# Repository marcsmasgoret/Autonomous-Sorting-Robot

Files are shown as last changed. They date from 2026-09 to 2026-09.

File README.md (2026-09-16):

**1. Problem Statement:**

The objective of this project is to design and develop a fully autonomous mobile robot capable of operating within a defined arena to locate, collect, and sort target objects under a strict 120-second time constraint. The robot must identify and collect green erasers while distinguishing them from non-target objects, then return to a designated home base where the objects are deposited and correctly sorted to maximize scoring performance. The system must function without any external control or intervention, relying entirely on onboard sensing, actuation, and control systems. The design is constrained by factors including limited operation time, physical size restrictions, onboard power supply, and the requirement for reliable autonomous navigation and object handling. The robot must efficiently traverse the arena, avoid obstacles, and consistently return to the base for deposition, while maintaining accurate sorting of collected objects. Scoring is directly dependent on both the quantity of target objects collected and the accuracy of their classification, making both efficiency and precision critical performance metrics. This problem reflects real-world engineering challenges in autonomous robotics, such as industrial material sorting, warehouse automation, and hazardous environment operations, where systems must operate independently and reliably without human intervention. The difficulty of the task lies in the integration of multiple subsystems—navigation, collection, sensing, and sorting—within tight constraints, while ensuring consistent performance despite uncertainties such as object positioning, sensor limitations, and mechanical interactions.

**2. Design Requirements & Constraints:**

The design requirements were developed to ensure that both the mobile robot and the stationary sorting system operate effectively within the given project constraints. The system integrates navigation, collection, and sorting subsystems, each with specific performance targets. Key requirements such as autonomous operation, reliable navigation using an IMU, and accurate color-based sorting guided the selection of components and overall system architecture. Feasibility of the design was validated through iterative prototyping and testing. Mechanical adjustments, including improved scoop clearance and weight reduction, enhanced system performance and reduced actuator load. Additionally, the use of a stationary sorting system improved classification reliability by providing controlled sensing conditions. Overall, the design meets the functional requirements within the constraints of time, power, and system complexity. Key quantitative constraints include a maximum operation time of 120 seconds, operation within a ~15 m² arena, and achieving a sorting accuracy target of at least 90%. [Design Requirements Table.xlsx](readme-assets/Design-Requirements-Table.xlsx)

**3. Program Plan:**

The project was completed over an eight-week period, following a structured and iterative development process. The timeline began with concept generation and selection, followed by mechanical design and CAD modeling of the chassis and scoop system. Prototype fabrication using 3D printing was then carried out, enabling initial testing of the drive, collection, and sorting subsystems. Testing played a critical role in identifying performance limitations, particularly in the scoop mechanism and object handling process. These issues led to a second design iteration, where mechanical refinements such as improved clearances and weight reduction were implemented. Programming and sensor integration were conducted concurrently with testing, reflecting the iterative nature of the development process. The critical path of the project included CAD modeling, prototype fabrication, and system testing, as delays in these stages directly impacted subsequent development. Overlapping tasks, such as programming and system testing, allowed for continuous refinement and improved overall efficiency. The project timeline also accounted for potential schedule variations and risks. Mechanical issues encountered during the initial prototype required redesign and reprinting, which introduced delays. To mitigate this, buffer time was effectively incorporated within the testing and iteration phases, allowing adjustments to be made without significantly affecting the final deadline. This ensured that system integration, final testing, and documentation were completed in time for the final showcase.
[Weekly Gantt Chart.xlsx](readme-assets/Weekly-Gantt-Chart.xlsx)

**4. Concept Generation:**

The system design was developed by decomposing the overall problem into key subsystems, including drivetrain, navigation, object collection, sorting, and homing. For each subsystem, multiple candidate concepts were generated using a combination of engineering reasoning and structured design approaches. This ensured that the final solution was not based on a single idea but rather selected from a diverse set of technically viable alternatives.

A range of concepts were explored for each major subsystem:

Drivetrain: Four-wheel drive, rear-wheel drive, and skid-steer configurations were considered to balance stability, maneuverability, and control complexity.
Navigation: IMU-based heading control, encoder-based tracking, and open-loop control were evaluated based on accuracy and implementation feasibility.
Object Collection: A scoop with rotary brush, conveyor belt system, and passive plow mechanism were explored to assess collection efficiency and object retention.
Sorting System: Both onboard sorting and a stationary base sorting system were considered, with variations in sensing and object handling mechanisms.
Homing Strategy: Ultrasonic-based positioning and alignment mechanisms were evaluated to ensure reliable return-to-base functionality.

Each concept was developed to the point of technical feasibility, ensuring that all candidate solutions were consistent with project constraints such as autonomous operation, time limitations, and system complexity.

**5. Concept Evaluation & Selection:**

The generated concepts were evaluated using structured engineering decision-making methods to determine the most effective overall system design. Three complete system-level concepts (Concept A, B, and C) were developed by combining different subsystem approaches for drivetrain, navigation, collection, and sorting. An initial Go/No-Go screening matrix was applied to eliminate concepts that failed to meet critical project requirements, such as reliable sorting performance, manageable mechanical complexity, and feasibility within the project timeline. Concepts that exhibited high risk in areas such as jamming, unreliable sorting, or excessive system complexity were rejected at this stage. The remaining concepts were then evaluated using a weighted decision matrix, where each design was assessed against key engineering criteria including collection efficiency, sorting accuracy, autonomous navigation performance, mechanical complexity, risk of failure, manufacturability, and system stability. Each criterion was assigned a relative weight based on its importance to overall system success, and concepts were scored accordingly. Through this evaluation process, Concept C achieved the highest overall score, demonstrating the best balance between performance, reliability, and implementation feasibility. Compared to alternative concepts, it reduced mechanical complexity on the mobile robot while improving sorting accuracy through the use of a stationary sorting system. Additionally, it minimized the risk of jamming and allowed for more controlled object handling during classification. The final selected concept integrates a scoop and rotary brush collection mechanism with IMU-assisted navigation and a stationary vibratory sorting system. This architecture was chosen because it enables efficient object collection while maintaining reliable and consistent sorting performance under controlled conditions, making it the most technically sound solution within the project constraints.

*TABLE 1:* Go/No-Go 

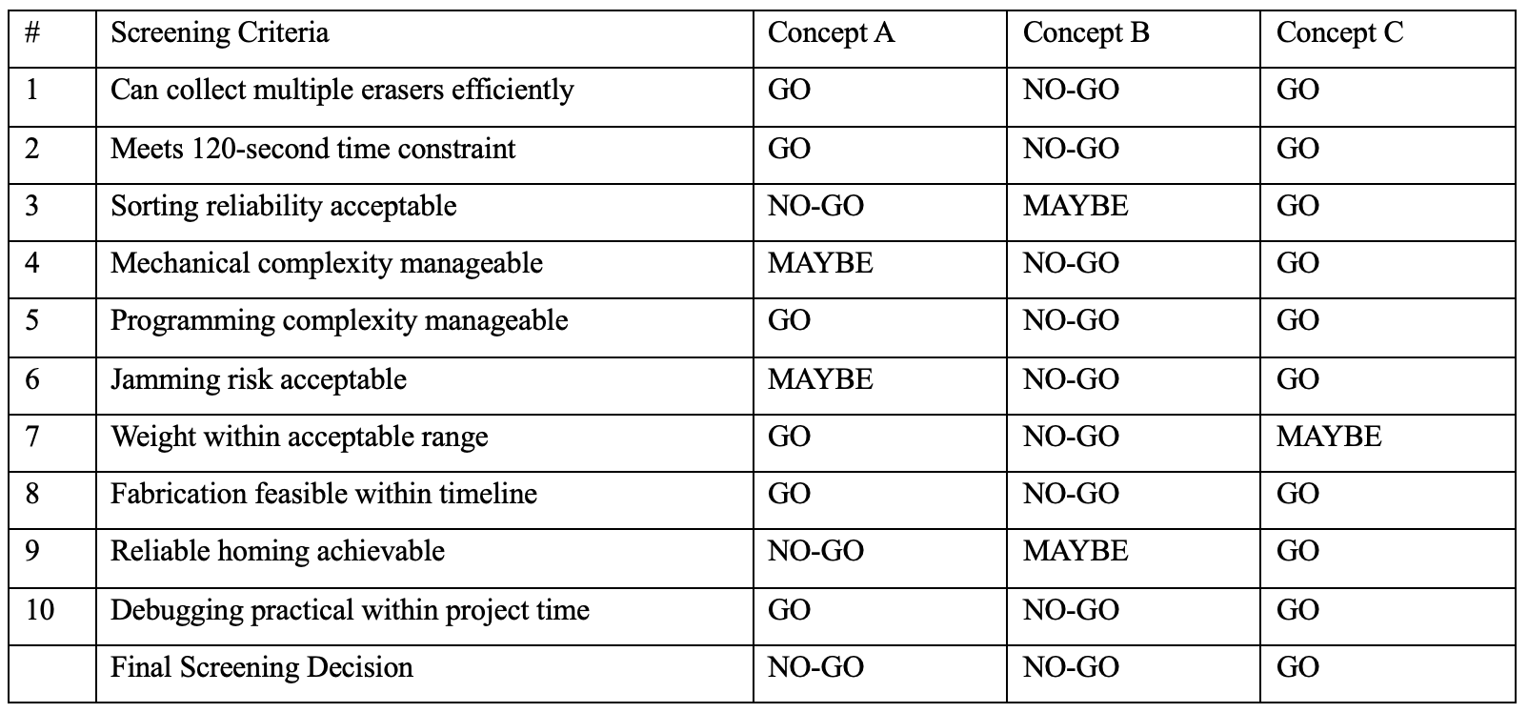
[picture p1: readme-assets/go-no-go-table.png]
Go-NoGo Table


*TABLE 2:* Weighted decision matrix comparing Concepts A, B, and C:

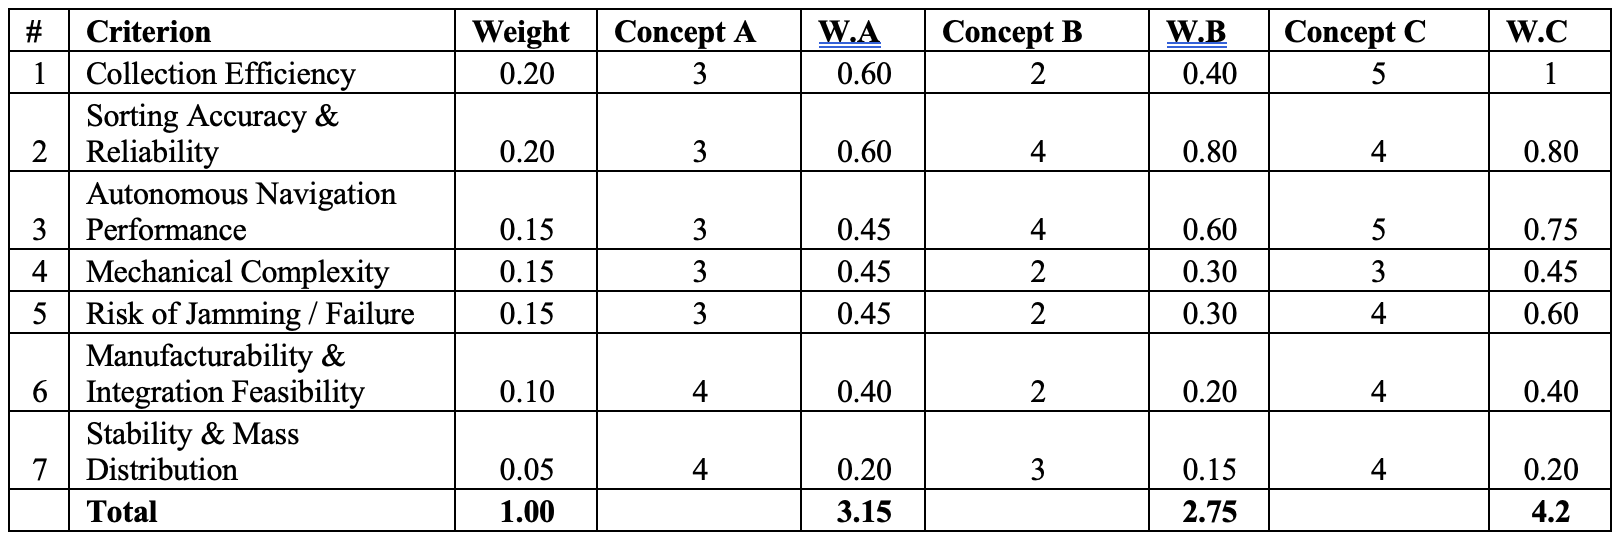
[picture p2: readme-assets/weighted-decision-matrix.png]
Screenshot 2026-04-07 at 11 14 16 AM


**6. Detail Design Development:**

The selected design was refined into a fully detailed system through iterative mechanical, electrical, and control development. The final system consists of a mobile robot for object collection and a stationary base for sorting, with each subsystem designed to meet specific performance requirements. The mechanical structure was developed using CAD modeling, focusing on a lightweight 3D-printed chassis to reduce actuator load while maintaining structural stability. The robot utilizes a rear-wheel drive configuration with two DC gear motors and front support wheels to improve maneuverability and turning accuracy. The scoop mechanism was designed as a servo-actuated lifting system, allowing controlled collection and retention of objects during reverse motion. Iterative redesigns increased internal clearance and reduced interference between components, significantly improving lifting performance and reliability. The collection subsystem integrates a rotary brush mechanism driven by a DC motor, which directs objects into the scoop during forward motion. The brush rotation was refined to reverse direction during backward movement, ensuring objects remain within the scoop and minimizing losses. These refinements were based on observed failures in early prototypes and demonstrate the application of iterative design principles. The navigation and control system incorporates an IMU for heading control and ultrasonic sensing for positioning relative to the base station. A state-based control strategy (collect → return → deposit) was implemented to coordinate system behavior and ensure consistent operation. The sorting subsystem was developed as a stationary system to improve classification accuracy. It consists of a vibrating platform to regulate object flow, a color sensor for detection, and a movable chute mechanism for directing objects. Design refinements addressed issues such as object clustering and sensor misreads by improving flow control and timing, resulting in more reliable sorting performance. All major components, including motors, sensors, structural elements, and actuation systems, were selected based on performance requirements, compatibility, and feasibility within project constraints. The final design demonstrates a fully integrated system where mechanical, electrical, and control subsystems function cohesively to achieve the desired operation.

*FIGURE 1:* Annotated SolidWorks top-view assembly drawing of the final scavenger robot:

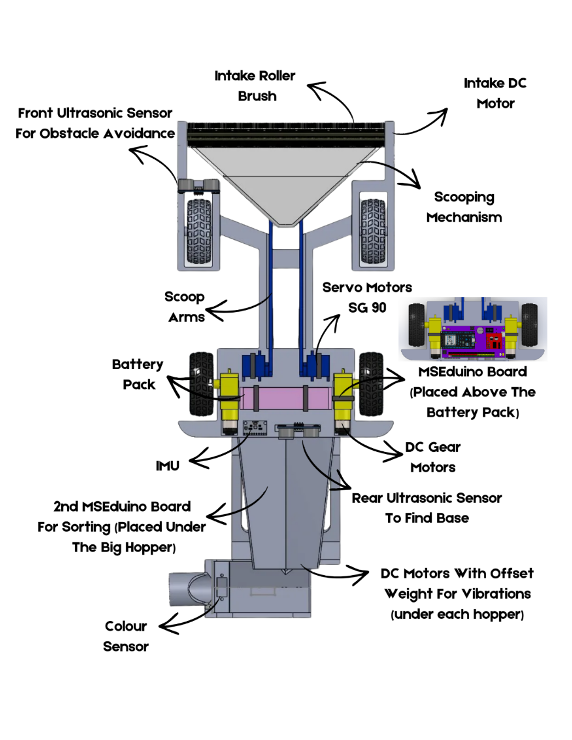
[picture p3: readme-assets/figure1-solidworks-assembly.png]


*FIGURE 2:* Scoop mechanism design evolution:

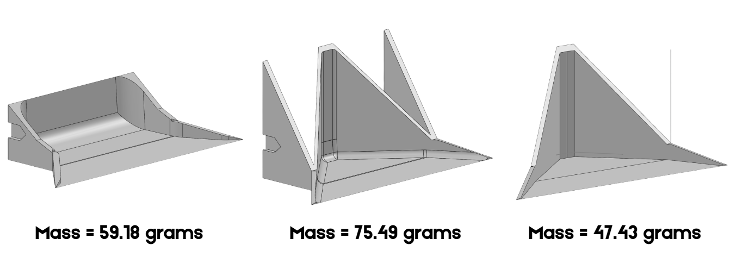
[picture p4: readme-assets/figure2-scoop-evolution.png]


*FIGURE 3:* Sorting System Final Design:

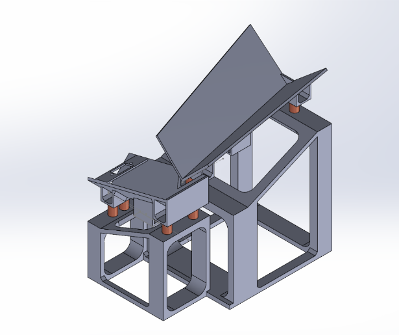
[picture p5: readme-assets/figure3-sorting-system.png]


*FIGURE 4:* System block diagram of the complete autonomous scavenger system:

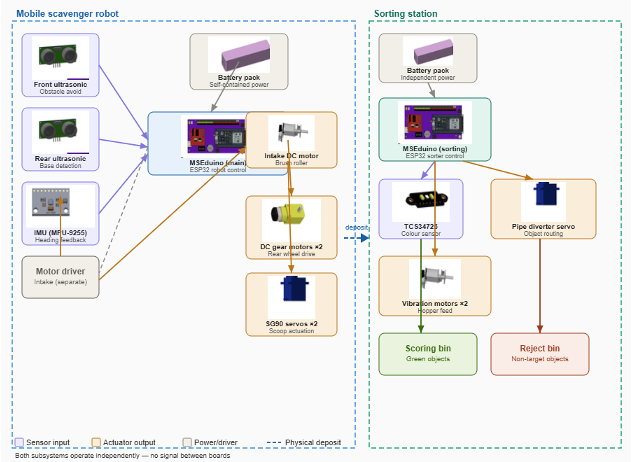
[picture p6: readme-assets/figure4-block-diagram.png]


**7. Design Analysis:**

The performance of the final design was evaluated through a combination of experimental results and engineering analysis of the system’s mechanical and sensing subsystems. The collection mechanism was assessed based on its ability to efficiently gather and retain objects. The rotary brush and scoop system demonstrated effective object capture, with brush rotation directing erasers into the scoop during forward motion. The introduction of reversed brush rotation during backward movement significantly reduced object loss. This indicates that the collection mechanism operates reliably under the expected operating conditions, with performance improvements directly resulting from iterative design refinements. The sorting subsystem was analyzed using calibrated sensor data and threshold-based classification. Experimental results showed that the normalized green value (0.4299) exceeded the detection threshold (0.40) by a margin of 0.10, providing clear separation from non-green objects. Multiple detection conditions were required to be satisfied simultaneously, and a temporal filtering method was implemented to improve robustness. As a result, no misclassification errors were observed across over 1000 tested samples, indicating high classification reliability under controlled conditions. The navigation system was evaluated based on heading stability and return-to-base performance. The use of an IMU enabled consistent orientation control, improving turning accuracy compared to open-loop methods. However, minor deviations in alignment were observed due to sensor drift and cumulative error, indicating moderate confidence in navigation precision. Overall, the system demonstrates high confidence in sorting performance, moderate confidence in navigation accuracy, and good reliability in object collection. The results confirm that the design meets the primary functional requirements, particularly in sorting accuracy and autonomous operation. Compared to alternative approaches such as onboard sorting, the selected stationary sorting system provides significantly improved sensing stability and classification accuracy. While more advanced navigation methods such as SLAM could improve positioning accuracy, they would introduce additional complexity without substantial benefit to overall system performance within the project constraints.

*FIGURE 5:* Calibration Table: The calibration data used to determine detection thresholds and validate color classification performance 

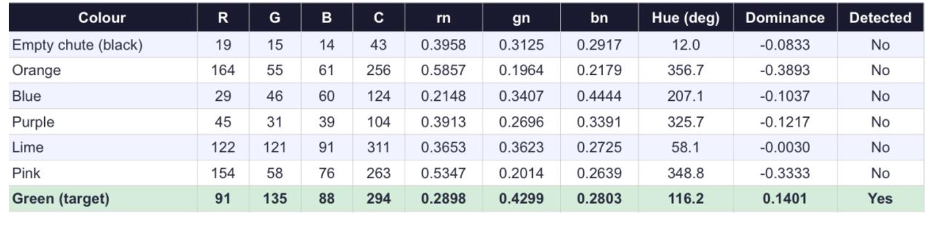
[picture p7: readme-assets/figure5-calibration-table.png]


*FIGURE 6:* Integrated full-system validation results: The integrated system performance results, including sorting accuracy and overall operation time

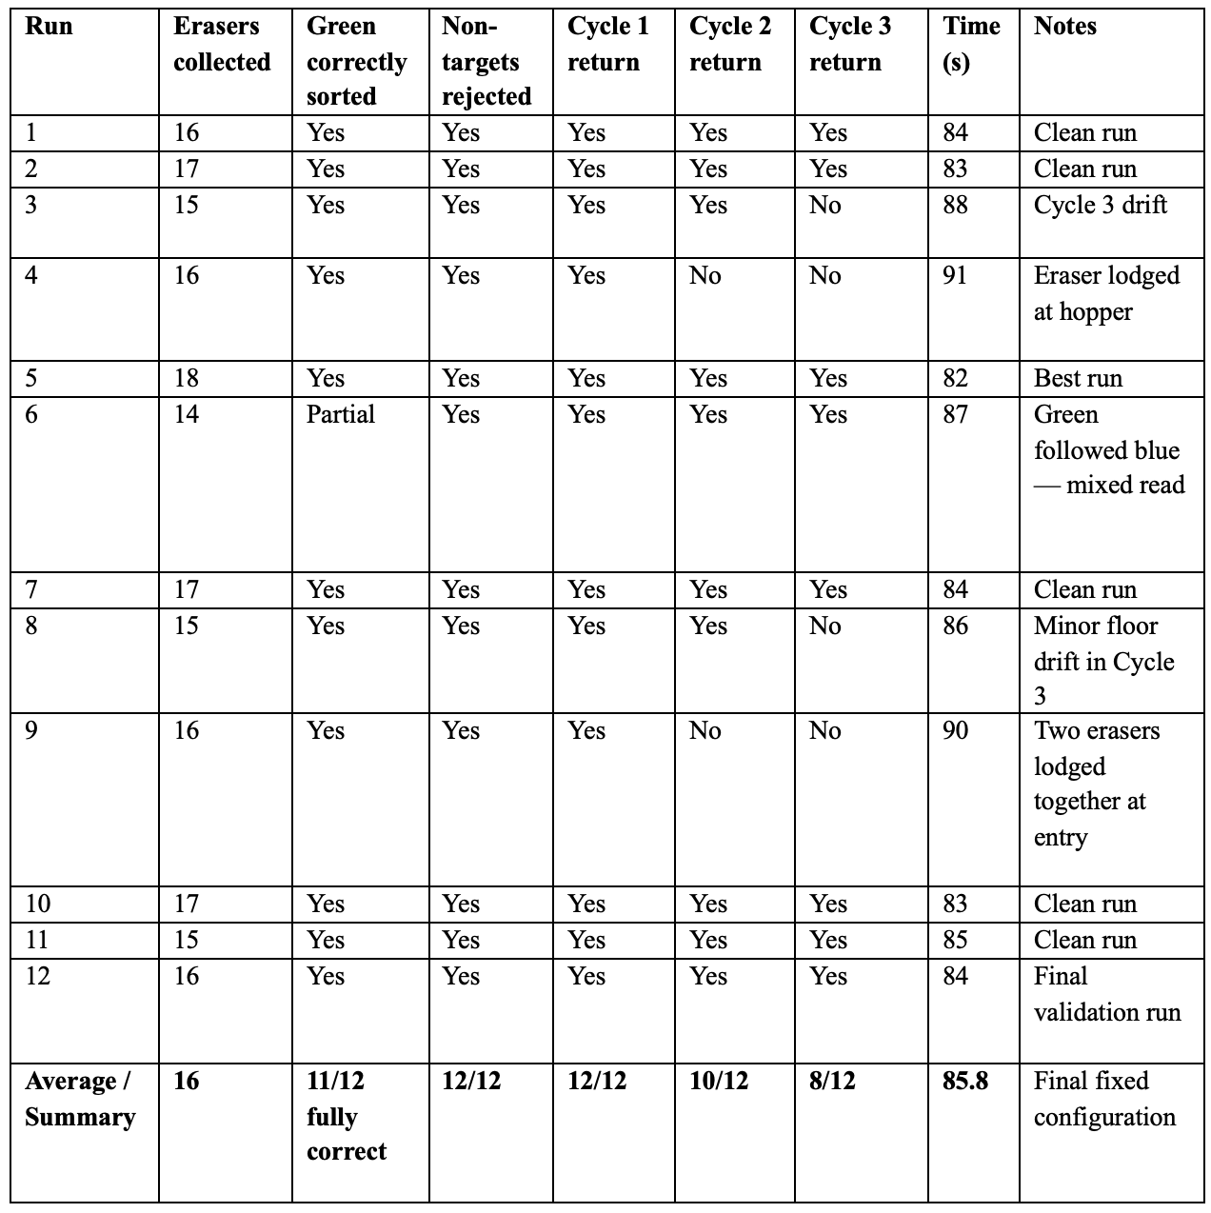
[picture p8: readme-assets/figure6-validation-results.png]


The results are considered valid within the tested conditions, as consistent measurements were obtained across repeated trials under controlled environmental conditions. These findings indicate that the selected design is highly effective for sorting tasks, which is the primary objective of the system. However, the moderate confidence in navigation accuracy suggests that positional errors may affect consistency in more complex environments.

**8. Design Documentation — Mechanical:**

Detailed mechanical design documentation was developed to fully define the final system configuration. This includes CAD models, assembly drawings, and component-level designs that describe the structure, geometry, and integration of all mechanical subsystems. The mechanical design consists of a lightweight 3D-printed chassis, a servo-actuated scoop mechanism, and a rotary brush collection system, all integrated into a stable four-wheel platform. The design was developed using CAD software, allowing for accurate dimensioning, component alignment, and interference checking during the design process. The provided drawings include detailed representations of key components such as the chassis, scoop assembly, brush mounting system, and sorting interface. These drawings define critical dimensions, clearances, and assembly relationships required for proper system operation. Iterative refinements were made to improve mechanical performance, including increased clearance for the scoop mechanism and reduction of excess material to minimize weight and actuator load. The mechanical design follows standard engineering practices, including clear dimensioning, consistent part definition, and organized assembly structure. Consideration was also given to manufacturing constraints, particularly those associated with 3D printing, such as material usage, part orientation, and structural support.

The complete set of mechanical design files is available in the following repository:

- [Engineering Drawings](Final%20CADs%20and%20Drawings/Engineering%20Drawings)  
- [Scavenger Robot CAD Models](Final%20CADs%20and%20Drawings/Scavenger%20CADs)  
- [Sorting System CAD Models](Final%20CADs%20and%20Drawings/Sorter%20CADs)

**9. Design Documentation — Electrical:**

The electrical design documentation defines the complete sensing, actuation, and control architecture of the system. This includes all electronic components, wiring configurations, and signal interfaces required for the operation of both the scavenger robot and the stationary sorting system. The system integrates multiple electronic components, including DC motors for drivetrain and brush actuation, servo motors for scoop and chute movement, an IMU for heading control, ultrasonic sensors for positioning, and a color sensor for object classification. These components are coordinated through a microcontroller-based control system to enable fully autonomous operation. Detailed wiring diagrams and circuit schematics were developed to ensure proper connectivity, power distribution, and signal integrity across all subsystems. Component selection was based on compatibility, performance requirements, and ease of integration within the overall system. Special consideration was given to voltage regulation, current limits, and reliable communication between sensors and actuators. The electrical design follows standard engineering practices, including clear labeling of components, organized wiring layouts, and modular subsystem integration. Consideration was also given to practical implementation constraints such as wiring management, noise reduction, and system reliability during operation.

The complete set of electrical design files is available in the following repository:
- [Control System Code](Final%20Code%20and%20Electrical/Code)
- [Electrical References and Component Documentation](Final%20Code%20and%20Electrical/Electrical%20References)

The bill of materials (BOM) provides a complete list of all mechanical and electrical components used in the system: [Lab 003 Team 1-BOM.xlsx](readme-assets/BOM.xlsx)

**10. Product Evaluation Results:**

The performance of the final system was evaluated through a series of experimental tests designed to assess its ability to meet the primary project objectives, including autonomous operation, object collection, sorting accuracy, and task completion within the required time limit. The system successfully completed the full autonomous operational cycle, demonstrating reliable integration of collection, navigation, and sorting subsystems. The system met the required time constraint and demonstrated strong sorting performance under controlled conditions. The use of a stationary sorting system contributed to improved classification stability and consistency.

The results are summarized in Figure 6, which presents the integrated system performance metrics, and in Table 6, which provides detailed validation results across multiple trials.

Testing was conducted through repeated trials under controlled conditions, with multiple erasers distributed within the arena to evaluate full system performance.

Subsystem testing confirmed that the drivetrain provided consistent motion, IMU-based heading control remained within acceptable drift limits, and ultrasonic sensing enabled reliable stopping near the base. The collection system achieved an average capture rate of 8–9 erasers per pass and maintained object retention during reverse motion. Sorting tests demonstrated accurate classification of green erasers and reliable rejection of non-target objects, with stable operation of the vibration and chute mechanisms.

Key performance results include:
- Task completion time: ~85.7 s (within 120 s requirement)
- Sorting accuracy: ~90–92%
- Misclassification: negligible under controlled conditions

While the system demonstrated strong overall performance, several limitations were identified during testing. Object clustering on the vibrating platform occasionally resulted in multiple erasers being processed simultaneously, which could affect sorting consistency. Additionally, navigation accuracy was influenced by IMU drift, leading to minor misalignment during return-to-base operations.

The results are considered reliable within the tested conditions and demonstrate strong validation of the system’s ability to meet the project objectives; however, performance may vary under different environmental conditions or increased system complexity.

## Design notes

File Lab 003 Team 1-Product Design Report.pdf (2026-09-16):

## Western University

## Faculty of Engineering

## Mechatronic Systems Engineering Program

## MSE 2202 – Introduction to Mechatronic Design

## Product Design Report

## Scavenger Robot Project: Welcome to Servo Buster

Lab 003 – Team 1

Group Members

Youssef El Kabat — 251370760

Marc Masgoret — 251412418

Eric Halim — 251241625

Dalia Salamah — 251402061

Date: April 2, 2026

Executive Summary

This report presents the design, development, and validation of an autonomous scavenger system for the

MSE 2202 term project. The objective was to design a compact, self-powered system capable of

autonomously collecting erasers from an unmarked arena, returning them to a base station, and sorting

target green erasers from non-target objects within a 120-second time limit.

The final design consisted of two coordinated subsystems: a mobile collection robot and a stationary

sorting subsystem at the base station. The robot used rear-wheel drive, a scoop-and-brush intake, IMU-

assisted navigation, and ultrasonic-based return positioning. The stationary sorter used a dual vibratory

feeder, a TCS34725 colour sensor, and a servo-actuated chute to classify deposited erasers under

controlled conditions. This architecture was selected because it reduced the mechanical complexity of the

robot while improving sorting reliability.

The design evolved significantly through testing and refinement. Major improvements included reducing

chassis weight, redesigning the scoop to lower servo loading, improving alignment at the base station, and

replacing the initial rotary sorting concept with a more reliable vibratory feeder. Validation testing

showed that the final system completed the full sequence of collection, return, unloading, and sorting in

an average of 85.7 s across the final 12 runs. Sorting accuracy reached 90–92% under controlled trials.

The main conclusion is that the final design provided a feasible and technically sound solution to the

project requirements. Future development should focus on improving object retention, return-path

accuracy, and single-file object feeding at the sorting station to further increase reliability and sorting

accuracy.

Table of Contents

1-Introduction

### 1.1 Design Problem

Autonomous robotic systems are increasingly deployed in environments where human operation is

unsafe, inefficient, or impractical — including hazardous material recovery, remote inspection, industrial

automation, and search-and-retrieval applications. In these contexts, the system must do more than

traverse an environment; it must reliably identify, collect, transport, and process objects of interest under

real operating conditions. The design challenge addressed in this project was the development of a

compact, self-powered autonomous scavenger system capable of completing a full collection-and-sorting

task without human intervention.

Per the project requirements, the system had to depart from a defined base location, gather valuable

objects from the ground within an operating area of up to 15 m², return to the base station, and deposit

only the target objects into a collection container — all within a maximum of 120 seconds. The system

was required to operate fully autonomously, with no painted lines, installed guides, tethered power

supplies, or external controllers, and had to be implemented using an ESP32-based microcontroller. The

complete assembly also had to remain compact enough to fit within an MSE locker without disassembly.

The operating surface was assumed to be relatively flat and bounded primarily at its perimeter, with no

major internal obstacles.

Beyond these stated requirements, the actual engineering problem was considerably broader. A successful

design had to simultaneously balance mobility, collection efficiency, object retention, sorting reliability,

manufacturability, mechanical simplicity, power constraints, and robustness under real operating

conditions. These competing demands motivated the adoption of a two-subsystem architecture: a mobile

scavenger robot responsible for navigation and object collection, paired with a stationary sorting

subsystem located at the base station. Although physically separate, the two subsystems were designed to

function as one unified solution. This architecture reduced the mechanical complexity and sensing burden on the mobile platform while improving the feasibility, calibration accessibility, and overall reliability of

the sorting stage.

### 1.2 Background Information

This project required the integration of several core mechatronic disciplines, including autonomous

navigation, ground-level object collection, and colour-based object classification. A review of relevant

approaches informed the final design decisions in each of these areas.

For small autonomous robots operating in bounded indoor environments, common navigation strategies

include dead reckoning, inertial heading control, line-following, infrared beacon homing, and vision-

based localization. Dead reckoning using wheel encoders is straightforward to implement but accumulates

positional error over time due to wheel slip and mechanical tolerances. Line-following eliminates drift but

requires pre-installed guides, which conflicts directly with the project constraints. Infrared beacon homing

offers a practical middle ground: it provides directional feedback toward a known target without requiring

external infrastructure, making it well-suited to the return-to-base phase of this task. For area coverage,

open-loop timed sweep patterns — while less precise than closed-loop localization — are robust,

computationally simple, and sufficient for bounded flat environments where obstacle density is low.

Ground-level object collection mechanisms for small robots include claws, plows, rotating brushes,

conveyor belts, scoops, and vacuum-based systems. Claw mechanisms allow targeted manipulation but

introduce actuation complexity and reduce collection throughput. Vacuum and conveyor systems support

continuous pickup but demand additional power, volume, and fabrication effort. Brush-and-scoop

arrangements represent an effective compromise: they are mechanically simple, tolerant of variability in

object position, and capable of gathering multiple objects rapidly — properties that are well-aligned with

the time-constrained scavenging task defined in this project.

Sorting of small, coloured objects can be achieved using photodiode-based colour sensing, RGB sensors,

or machine vision. RGB colour sensors such as the TCS34725 provide reliable hue discrimination at low

cost and with minimal computational overhead, making them appropriate for embedded systems with

limited processing resources. Sorting can be implemented either onboard the mobile robot or via a

stationary system at the base station. Onboard sorting minimises transfer steps but increases the robot's

weight, sensing complexity, and packaging constraints. A stationary sorter, by contrast, allows objects to

be presented to the sensor in a controlled, repeatable manner, improving classification accuracy and

simplifying calibration. For an academic prototype operating under a fixed budget and timeline, the

stationary approach offers a more reliable and maintainable solution.

More sophisticated approaches — including encoder-based odometry with sensor fusion, simultaneous

localization and mapping (SLAM), or convolutional neural network-based vision classification — could

improve adaptability and spatial precision. However, these methods introduce significant hardware cost,

computational overhead, and development complexity that were inconsistent with the available resources

and project timeline. The final design therefore prioritised practical robustness and subsystem modularity

over algorithmic sophistication.

### 1.3 Project Objectives and Scope

The objective of this project was to design, fabricate, and validate a complete autonomous scavenger

system capable of collecting target objects from an unmarked floor area and ensuring that only the desired

objects were deposited into the final collection container. Functionally, the completed system had to:

1. Navigate autonomously through the operating area without external guides or remote control

### 2. Collect multiple objects from the ground efficiently within the mission time limit

### 3. Transport collected objects back to the base station

4. Sort the collected objects such that only target items were retained in the final collection stage

Expressed in quantitative engineering terms, the system was required to complete the full task within 120

seconds, operate entirely on the onboard power bank included in the MSE 2202 Lab Kit, use an ESP32-

based microcontroller for all control functions, remain within the physical envelope of an MSE locker

without disassembly, and be fabricated within a combined additional component budget of $50. The

project scope encompassed concept generation and selection, CAD-based design development, prototype

fabrication, electrical and software integration, and performance testing against the defined specifications.

These objectives were achievable within the available timeframe because the final architecture

deliberately decomposed the overall mission into two cooperating subsystems — a mobile robot

optimised for navigation and collection, and a stationary sorter optimised for classification and final

deposition — each of which could be developed, tested, and refined in parallel.

### 2. Discussion

### 2.1 Concept Generation and Selection

A structured concept generation process was used to develop the final system architecture. Rather than

selecting a complete robot concept immediately, the overall problem was first decomposed into major

functional subsystems: drivetrain, navigation and heading control, environment sensing, search strategy,

object collection, sorting location, sorting mechanism, homing, object deposition, and structural

packaging. Multiple concepts were generated for each subsystem independently to explore a broad design

space before committing to an integrated solution. This approach ensured that final concept selection was

grounded in engineering trade-offs rather than intuition alone. Alternatives considered during the

Milestone 1 concept generation phase included front-wheel, all-wheel, and three-wheel drive layouts;

open-loop, encoder-based, and IMU-based motion control; random-walk, lawnmower, and spiral

coverage strategies; onboard versus base-station sorting; and multiple collection and deposition

mechanisms.

At the subsystem level, each selected concept was chosen on the basis of its balance between

performance, reliability, simplicity, and feasibility within the course timeline and budget. For locomotion,

a four-wheel all-wheel-drive layout was identified as the preferred concept in Milestone 1 because it

offered improved traction, stability, and turning control while pushing a front-mounted collection

mechanism. For navigation, IMU-based heading feedback was selected over open-loop PWM control and

encoder-based speed matching because it improved directional consistency without introducing the

encoder mounting and tuning challenges associated with wheel-speed feedback on a compact platform. A

single ultrasonic sensor was selected for obstacle detection on the grounds that the competition arena was

assumed to be relatively open and flat, making a simple single-axis sensing configuration sufficient for

safe autonomous operation. A lawnmower-style zig-zag coverage strategy was chosen because it offered

more predictable area coverage than a random walk and lower implementation complexity than a spiral or

perimeter-inward strategy. For sorting, a stationary base-station sorter was preferred over onboard sorting

because it reduced the mass and mechanical complexity of the mobile robot while simultaneously creating

more controlled and repeatable sensing conditions for object colour classification. Within the base-station

sorting category, two distinct mechanisms were evaluated: a motorised rotary indexing disc with radial

ridges intended to capture and index erasers one at a time, and a dual vibratory feeder with a servo-

actuated bifurcated chute. The rotary disc was rejected after physical testing revealed that the compliant

and irregular surface geometry of the erasers prevented consistent single-object indexing, making the

vibratory feeder the stronger candidate.

These selected subsystem concepts were then assembled into three complete system-level concepts for

comparative evaluation. Concept A used a scoop with active intake, infrared beacon homing, and a

gravity-based ramp sorter with a servo-controlled gate. Concept B used a six-wheel skid-steer platform,

claw-based pickup, onboard sorting, and encoder-based homing. Concept C used a four-wheel-drive

chassis, scoop-based collection with active brush intake, IMU-assisted navigation, and a stationary base

sorting station with colour sensing and active servo diversion. Concept C was selected because it provided the strongest overall balance between collection efficiency, sorting reliability, navigation performance,

and integration feasibility. Compared with Concept A, it reduced sensitivity to gravity timing and

trapdoor alignment by using a more controlled vibration-assisted transfer and diverter-based sorting

process. Compared with Concept B, it avoided the high mechanical and programming complexity

associated with claw-based pickup and onboard real-time object discrimination. A Go/No-Go screening

eliminated Concepts A and B due to unacceptable risk in sorting reliability, homing robustness, and

mechanical complexity, while Concept C passed all mandatory screening criteria. This result was

subsequently confirmed by a weighted decision matrix, in which Concept C received the highest total

score of 4.20, compared with 3.15 for Concept A and 2.75 for Concept B.

From an engineering standpoint, the selection of Concept C was justified primarily because it separated

the overall mission into two cooperating but independently optimised subsystems. The mobile robot was

optimised for motion, collection, and return-to-base behaviour, while the stationary sorter was optimised

for controlled object presentation and classification. This separation reduced the number of interacting

mechanisms that had to function simultaneously on the robot, lowered the risk of onboard jamming or

sensing interference, and improved the likelihood of completing the full mission within the 120-second

time constraint. The architecture was also more realistic to fabricate, debug, and refine within the

available time and course resources than either alternative. The concept selection process therefore

identified not only a feasible design direction but also demonstrated why it represented the most

practically sound and technically balanced solution among the candidates considered.

While Concept C was selected as the foundation for further development, the final prototype was not a

direct one-to-one implementation of the original conceptual design. As prototyping and subsystem testing

progressed, several elements of the concept were refined to improve manufacturability, reduce weight,

simplify integration, and increase overall reliability. These refinements included changes to the drivetrain

layout, chassis structure, scoop geometry, unloading method, and collection sequence. Concept C should therefore be understood as the selected design direction, while the final prototype represents its optimised

and experimentally refined implementation.

Table 1: Go/No-Go screening matrix applied to the three system-level design concepts. Concepts A and

B were eliminated due to unacceptable risk in sorting reliability, homing robustness, and mechanical

complexity. Concept C passed all mandatory screening criteria and was selected for further development.

# | Screening Criteria | Concept A | Concept B | Concept C

1 | Can collect multiple erasers efficiently | GO | NO-GO | GO
2 | Meets 120-second time constraint | GO | NO-GO | GO
3 | Sorting reliability acceptable | NO-GO | MAYBE | GO
4 | Mechanical complexity manageable | MAYBE | NO-GO | GO
5 | Programming complexity manageable | GO | NO-GO | GO
6 | Jamming risk acceptable | MAYBE | NO-GO | GO
7 | Weight within acceptable range | GO | NO-GO | MAYBE
8 | Fabrication feasible within timeline | GO | NO-GO | GO
9 | Reliable homing achievable | NO-GO | MAYBE | GO
10 | Debugging practical within project time | GO | NO-GO | GO
| Final Screening Decision | NO-GO | NO-GO | GO

Table 2: Weighted decision matrix comparing Concepts A, B, and C across seven engineering criteria.

Weights were assigned based on relative importance to mission success. Concept C achieved the highest

weighted total score of 4.20, confirming the Go/No-Go screening result.

# | Criterion | Weight | Concept A | W.A | Concept B | W.B | Concept C | W.C

1 | Collection Efficiency | 0.20 | 3 | 0.60 | 2 | 0.40 | 5 | 1
2 | Sorting Accuracy & Reliability | 0.20 | 3 | 0.60 | 4 | 0.80 | 4 | 0.80
3 | Autonomous Navigation Performance | 0.15 | 3 | 0.45 | 4 | 0.60 | 5 | 0.75
4 | Mechanical Complexity | 0.15 | 3 | 0.45 | 2 | 0.30 | 3 | 0.45
5 | Risk of Jamming / Failure | 0.15 | 3 | 0.45 | 2 | 0.30 | 4 | 0.60
6 | Manufacturability & Integration Feasibility | 0.10 | 4 | 0.40 | 2 | 0.20 | 4 | 0.40
7 | Stability & Mass Distribution | 0.05 | 4 | 0.20 | 3 | 0.15 | 4 | 0.20
| Total | 1.00 | | 3.15 | | 2.75 | | 4.2

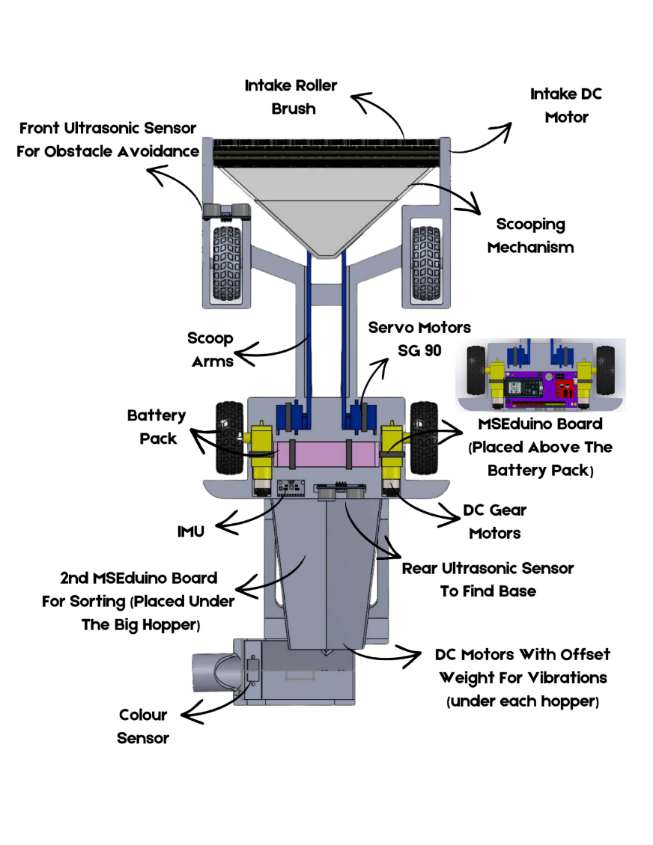
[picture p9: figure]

Figure 1: Annotated SolidWorks top-view assembly drawing of the final scavenger robot, identifying all

major subsystems including the intake roller brush, scooping mechanism, scoop arms, SG90 servo

motors, DC gear motors, IMU, front and rear ultrasonic sensors, battery pack, MSEduino control boards,

and vibration motors.

### 2.2 Detailed Design and System Implementation

The final design comprised two coordinated subsystems: a mobile collection robot and a stationary

sorting station, each optimised for its specific function within the overall mission. The detailed design

process focused on refining both subsystems into a manufacturable and functional final product that could

be built within the available time, budget, and fabrication constraints while operating reliably as one

integrated system.

Mobile Robot — Drivetrain and Chassis

The mobile robot was designed around a compact wheeled chassis with a front-mounted collection

mechanism and a rear section housing the drive system, electronics, and structural support. In the refined

final design, the robot used two powered rear wheels driven by DC gear motors, with passive front support wheels providing stability. Differential motor control enabled forward motion, reversing, and

turning. This rear-wheel-drive layout represented a deliberate simplification from the all-wheel-drive

concept originally selected in Milestone 1. The change was justified on the grounds that the operating

surface was smooth and flat, making the additional traction and mechanical complexity of all-wheel drive

unnecessary. The simplified layout reduced wiring complexity, current draw, and fabrication effort while

maintaining adequate mobility for the defined arena conditions.

The chassis underwent three distinct design iterations during prototyping. The first iteration used a broad

board-style structure with recessed indentations intended to simplify integration of electronic components,

side panels, and the scoop assembly. While functional for early testing, this layout introduced

unnecessary structural material and therefore excessive mass. A second iteration retained the indentation-

based packaging concept but reduced overall thickness and consolidated the component arrangement into

a tighter footprint. Although this improved packaging density, further testing during milestone validation

revealed that the platform could be simplified more substantially. The final chassis adopted a skeletal

structure retaining only the essential load-bearing geometry. Electronics were arranged compactly at the

rear alongside the drive motors, and custom 3D-printed retaining pins secured components without

additional fastener hardware. This progressive mass reduction improved the power-to-weight ratio of the

robot and reduced the actuation load on the scoop-lifting servos.

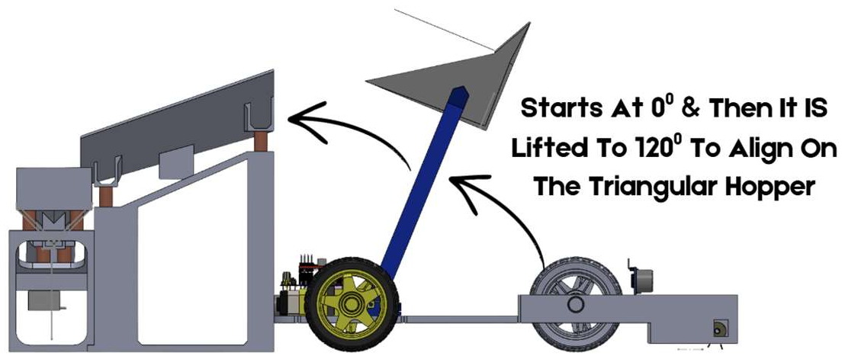
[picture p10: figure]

Figure 2: SolidWorks side-view assembly drawing of the scavenger robot showing the scoop mechanism

in the raised (deposit) position. The arrow indicates the rotational travel of the servo-driven scoop arms

from the lowered collection position to the raised unloading position.

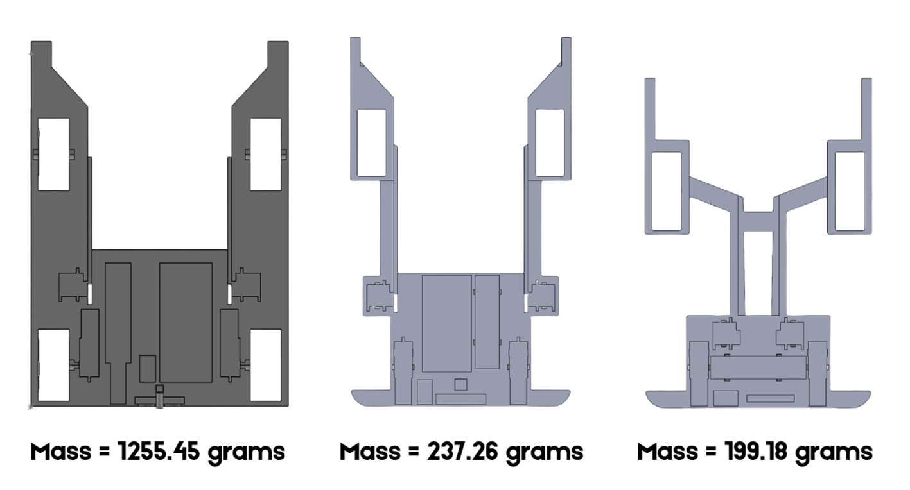
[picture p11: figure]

Figure 3: Chassis design evolution across three prototype iterations. Left: first-generation broad board

chassis with recessed component indentations. Centre: second-generation reduced-thickness chassis with

consolidated component layout. Right: final skeletal chassis retaining only essential load-bearing

geometry, with 3D-printed retaining pins replacing conventional fastener hardware.

Mobile Robot — Object Collection

Object collection was achieved using a front scoop combined with an active rotary brush. The scoop

provided a wide ground-level capture area and funneled erasers toward the intake region as the robot

advanced. The brush, constructed from pipe-cleaner bristles and driven by a DC motor, rotated inward

during forward travel to pull scattered erasers into the scoop more effectively than a passive plow alone.

This arrangement increased collection probability and allowed multiple erasers to be gathered

continuously during a single forward pass. During reverse motion, the scoop was raised and brush

rotation was coordinated to retain collected objects and prevent them from escaping the scoop cavity. This

coordinated scoop-and-brush interaction allowed the same front mechanism to serve both collection and

containment functions, reducing the need for a separate internal transfer system.

The scoop mechanism also underwent substantial redesign between prototype iterations. Early versions

used a wide rectangular scoop supported by arms mounted near the outer edges of the chassis. Testing

revealed two significant problems with this arrangement. First, insufficient arm clearance caused the scoop arms to rub against the chassis structure during lifting, imposing excessive frictional load on the

servos and risking overheating or stall. Second, the scoop's own mass was high enough to challenge servo

lifting capacity before any eraser payload was added. To address both issues, the scoop was redesigned to

be significantly lighter and tapered to better match the triangular entry geometry of the sorting station,

improving unloading efficiency and reducing the probability of erasers missing the vibratory feeder

during the deposition step. The scoop arms were relocated inward toward the chassis centreline to

eliminate wall contact during travel, and their geometry was adjusted to reduce the mechanical tension

generated by an overly wide mounting span. A transverse connecting beam was added between the two

arms, enabling both servo-driven sides to share the lifting load, improving symmetry of motion, and

reducing torsional twisting under payload. Collectively, these changes reduced the effective torque

demand on the servo system and improved the reliability of the lifting and unloading cycle.

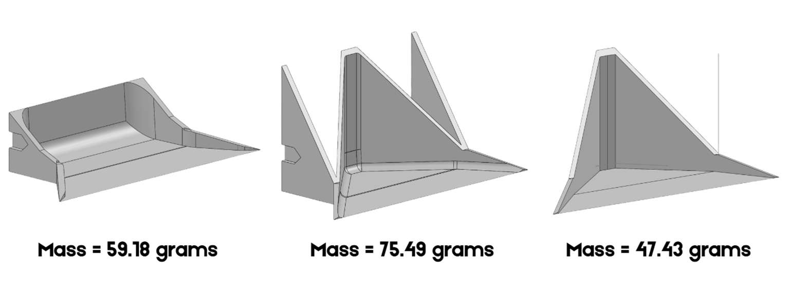
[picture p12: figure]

Figure 4: Scoop mechanism design evolution. Left: original wide rectangular scoop with outboard arm

mounting, which caused chassis wall contact and excessive servo loading during lifting. Right: final

tapered scoop profile with inboard arm relocation, transverse connecting beam, and reduced structural

mass, restoring reliable servo operation within the rated torque margin.

Mobile Robot — Navigation and Return-to-Base

The robot performed search coverage under IMU-assisted heading control, with the strategy evolving

across prototype stages. The initial lawnmower-style zig-zag pattern deposited too many erasers simultaneously and overloaded the scoop servos, and was refined into the three-cycle fan-shaped path

described below. In both implementations, the IMU was calibrated at the start of each run and heading

corrections applied throughout motion to maintain directional consistency. A rear-mounted ultrasonic

sensor detected proximity to the sorting station and triggered the stop-and-deposit sequence. A V-shaped

alignment wall — two flat walls angled at 50 degrees — provided passive lateral correction during

reverse approach: the filleted chassis corners contacted the walls and self-centred the robot without any

active software correction.

Figure 5: SolidWorks drawing of the V-shaped base

station alignment walls, showing the two flat walls

angled at 50 degrees forming a passive docking guide.

The filleted chassis corners of the robot contact and slide

along the walls during reverse approach, self-correcting

any lateral offset until the robot is centred and the

ultrasonic sensor confirms contact with the base.

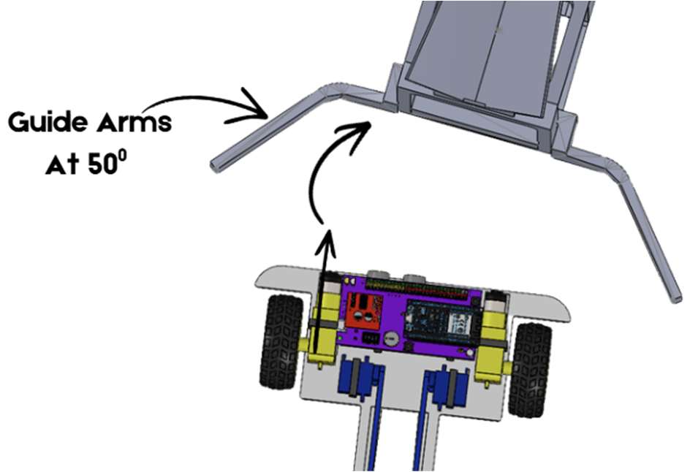
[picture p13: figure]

Collection Strategy — Multi-Cycle Operation

The overall collection strategy was refined during integration testing from a single extended pass to a

multi-cycle sequence of shorter collection-and-deposition runs. In the final control sequence, the robot

began at the base station and executed three distinct collection cycles. Cycle 1 drove straight forward

along the central corridor and reversed directly back to the base to deposit. Cycle 2 turned approximately

45 degrees to the right before advancing forward, then reversed back to the deposit point and realigned.

Cycle 3 mirrored this on the left side. Together, the three cycles formed a fan-shaped coverage pattern

across the full width of the arena, as shown in Figure 6. This staged approach offered two key engineering

advantages. First, it allowed the sorting mechanism to begin processing earlier deposits while the robot

continued collecting, improving the effective use of the 120-second mission window. Second, it capped

the maximum scoop payload per cycle, reducing peak servo loading and preventing the sorter from being overwhelmed by a large simultaneous deposit. In practice, this multi-cycle strategy improved both

mechanical reliability and sorting throughput consistency.

Figure 6: Motion sequence diagram showing the

three-cycle collection path executed by the robot

within the operating arena. Cycle 1 follows a

straightforward-and-return path along the central

corridor; Cycles 2 and 3 follow right and left

diagonal paths respectively, forming a fan pattern

that covers the full arena width. Solid lines

indicate forward collection passes; dashed lines

indicate reverse return to the base station.

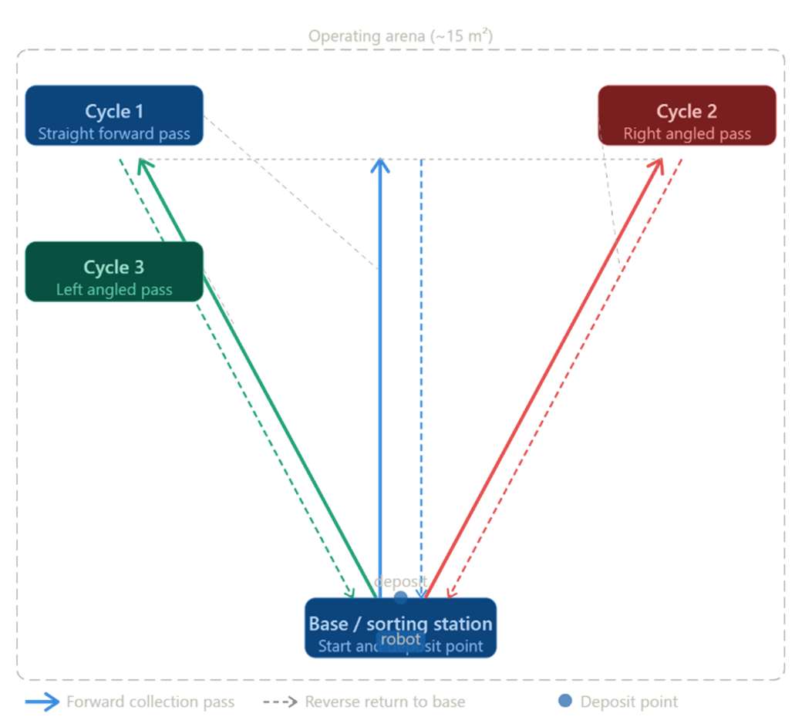
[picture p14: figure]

Sorting System:

Once the mobile robot deposited its collected load at the base station, object classification and final

deposition were handled entirely by the stationary sorting subsystem. The sorting station underwent a full

architectural redesign between prototype stages after early testing revealed that the initial concept could

not provide reliable single-object presentation to the sensor. The final design process therefore focused on

selecting a sorting mechanism that could be fabricated with available resources, tuned experimentally, and

integrated consistently with the unloading behaviour of the robot.

The initial sorting concept used a motorized rotary indexing disc mounted on an inclined tripod frame,

with extruded radial ridges sized to capture one eraser at a time. As the disc rotated, erasers were intended

to be captured in the inter-ridge pockets and indexed individually into a blast-gate assembly, where a

TCS34725 colour sensor would trigger a servo-actuated chute to sort them left (non-target) or right

(green). However, physical testing showed that this concept could not reliably isolate individual erasers.

Due to the compliant surface and irregular orientation of the erasers, the ridges would sometimes capture multiple objects or none. Without a controlled upstream feeding mechanism, the system could not

guarantee one-at-a-time delivery and was therefore rejected in favour of a different architecture.

Figure 7: Initial rotary indexing disc sorting concept.

The final sorting station used a dual-stage vibratory feeder, a

colour sensing stage, and a servo-actuated bifurcated output

chute. Each of the two inclined funnel platforms was driven by a

DC motor mounted beneath it and supported by stiff compression

springs, which provided the restoring force for consistent

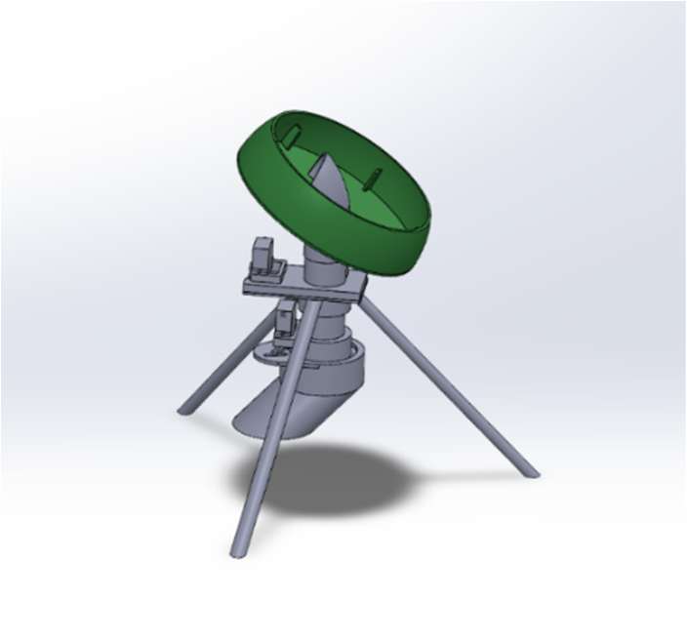
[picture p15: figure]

oscillatory motion. The stock 400:1 gearboxes were removed from both motors so the shafts could rotate

at higher speed, and an eccentric offset weight was attached to each shaft to generate high-frequency

vibration. This vibration disaggregated clustered erasers and promoted progressive single-file

advancement toward the sensing chute. The final sorting station was built primarily from 3D-printed

structural components and integrated a TCS34725 colour sensor for object classification, two modified

DC motors with eccentric masses for vibratory feeding, stiff compression springs for controlled

oscillation, and a servo-actuated chute for final object diversion. These components were selected because

they provided a practical balance between simplicity, tunability, and reliable operation within the

available fabrication methods and project budget.

Figure 8: Final dual vibratory feeder sorting system.

Funnel angle proved to be a critical tuning parameter.

Initial steep angles generated excessive eraser momentum

and caused clustering at the sensing stage. After iterative

testing, an angle of 16° from horizontal was established as

optimal for both funnels, allowing gravity-driven

advancement at a controlled rate. The two motors were

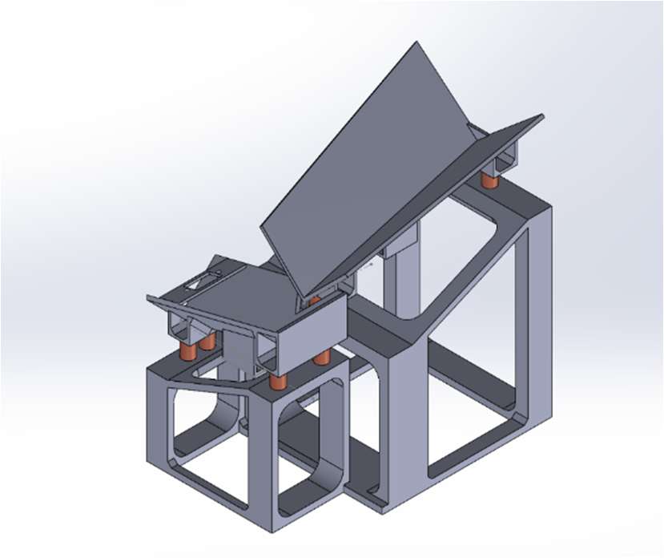
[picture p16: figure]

operated in an alternating offset pattern, with the upper funnel active while the lower was inactive and vice versa, so that erasers arrived at each stage with dissipated momentum. Both motors were driven at

maximum PWM (255/255), which produced the most controlled and repeatable feeding behaviour.

At the base of the lower funnel, the TCS34725 colour sensor classified each eraser using calibrated RGB

threshold values established during sensor testing. In the final implementation, an eraser was classified as

green when the normalized green ratio exceeded 0.40 and the green-dominance term was positive. This

rule was selected because the target green eraser produced a normalized green value of 0.4299 with

positive dominance, while all non-target test objects produced lower normalized green values and non-

positive dominance under the same sensing conditions. Objects that did not satisfy this condition were

rejected by default, ensuring that sensor uncertainty resulted in missed green erasers rather than false

acceptance of non-target objects.

Across 100 successive sorting trials, the final sorting system achieved 90–92% classification accuracy.

The primary failure mode was eraser clustering at the sensing stage, where two objects entering

simultaneously could produce a composite reading and occasional misclassification. A secondary

limitation was base-station drift under sustained vibration, which was temporarily managed during the

showcase by securing the unit to the surface. Despite these limitations, the achieved accuracy was

considered acceptable for the scope of the project.

### 2.3 Design Analysis

The final design was evaluated from the perspectives of collection efficiency, mechanical feasibility,

sorting reliability, and overall system integration. Given the academic project context, the analysis

focused on whether the selected architecture achieved a realistic and defensible balance between

performance and reliability, combining qualitative engineering reasoning with targeted quantitative

assessments where practical measurements were available.

System-Level Architecture

The most consequential design decision was the separation of the full mission into two coordinated

subsystems. By assigning collection, navigation, and transport exclusively to the mobile robot, and classification and deposition exclusively to the stationary sorter, the architecture reduced the number of

simultaneous sensing, actuation, and timing demands placed on any single unit. Relative to the onboard

sorting architecture of Concept B, this arrangement was expected to yield a higher probability of mission

completion within 120 seconds because the robot could optimise for collection speed without also

managing real-time object discrimination. Relative to the passive gravity-fed sorting of Concept A, it

offered greater control over object presentation to the colour sensor, since vibration-assisted feeding and

active servo diversion are less sensitive to ramp angle tolerance and precise gravitational timing than a

purely passive gate system. The sorting station itself also underwent a full internal architectural redesign

between prototype stages, moving from a rotary indexing disc concept to a dual vibratory feeder

arrangement, further demonstrating that the two-subsystem architecture provided the modularity to

completely replace the sorting mechanism without any modification to the mobile robot — validating a

key structural advantage of the selected concept. These comparisons support the conclusion that the

selected architecture represented the most robust, modular, and controllable option among those

evaluated.

Table 3: Quantitative and qualitative performance comparison between the three evaluated system-level

concepts across key engineering criteria. Concept C is the only concept for which validated sorting

accuracy data is available, as Concepts A and B were eliminated prior to prototype construction.

Criterion | Concept A | Concept B | Concept C (Selected)
Weighted decision score | 3.15 | 2.75 | 4.2
Sorting method | Passive gravity gate | Onboard real-time sorting | Dual vibratory feeder
Navigation method | IR beacon homing | Encoder-based return | IMU-assisted heading
Collection method | Active scoop intake | Claw-based pickup | Scoop + brush intake
Sorting architecture iterations | 1 | 1 | 2 (rotary disc → vibratory feeder)
Onboard mechanical complexity | Medium | High | Low–Medium
Jam risk assessment | High | Very high | Low
Sorting accuracy (validated) | Not tested | Not tested | 90–92%
Fabrication feasibility | Medium | Low | High
Passed Go/No-Go screening | No | No | Yes

Figure 9: System block diagram of the autonomous

scavenger system, showing sensor inputs, the

ESP32-based controller, motor driver, actuator

outputs, onboard power supply, and the object

transfer path between the mobile robot and sorting

station.

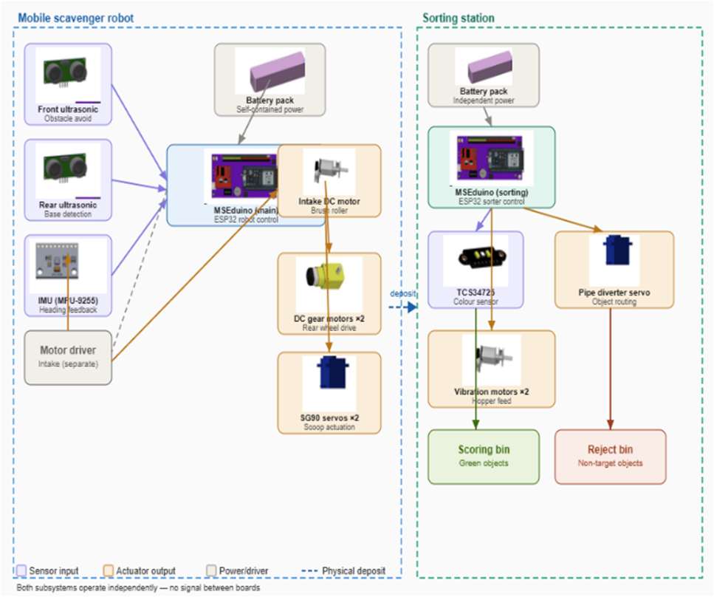
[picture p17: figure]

Mechanical Feasibility — Actuator Loading

A key mechanical concern throughout prototyping was the load imposed on the scoop-lifting servo

system. The SG90 micro servo used for scoop actuation has a rated stall torque of 1.8 kg·cm (176.5

N·mm). Using the static torque relationship T = mgL, where m is the combined scoop and payload mass

and L is the arm length from pivot to load point (178.5 mm), the torque demand of the original design was

calculated as:

T₁ = (0.07549 + 0.018) × 9.81 × 0.1785 = 0.1638 N·m (163.8 N·mm)

This represented 92.8% of the servo's stall torque — a critically small operating margin that directly

explained the observed servo stall failures during early prototype testing. Following the scoop redesign,

the reduced scoop mass of 47.43 g yielded a revised torque demand of:

T₂ = (0.04743 + 0.018) × 9.81 × 0.1785 = 0.1146 N·m (114.6 N·mm)

This corresponds to 64.9% of stall torque, restoring a safe operating margin and representing a 30.0%

reduction in torque demand relative to the original design. The addition of the bilateral connecting

beam between the scoop arms further distributed this load across both servos, improving symmetry and

reducing the risk of asymmetric stall. These calculations confirm that the scoop redesign was not merely a qualitative improvement but a quantitatively necessary correction to bring the actuation system within its

reliable operating range.

Figure 10: Handwritten calculation of servo torque demand before and after scoop redesign. The original

design operated at 92.8% of the SG90 stall torque rating, explaining observed servo stall failures. The

redesigned scoop reduced torque demand to 64.9% of stall torque, representing a 30.0% reduction and

restoring a reliable operating margin.

Sorting Station — Flow Control and Classification Confidence

The sorting station was analysed in terms of object flow regularity and classification reliability. As

described in Section 2.2, the initial rotary disc was abandoned when eraser compliance prevented

consistent single-object indexing. The dual vibratory feeder resolved this by converting bulk deposits into

a controlled single-file stream before the TCS34725

sensing region. Classification confidence depended on

calibrated funnel angle (16 degrees), alternating motor

offset pattern, and maximum PWM (255/255). The fail-

safe default of left-diversion for all unclassified objects

ensured sensor failures produced missed green erasers

rather than non-target contamination. Across 100

successive trials the system achieved 90–92% accuracy,

with simultaneous dual-object arrival as the primary

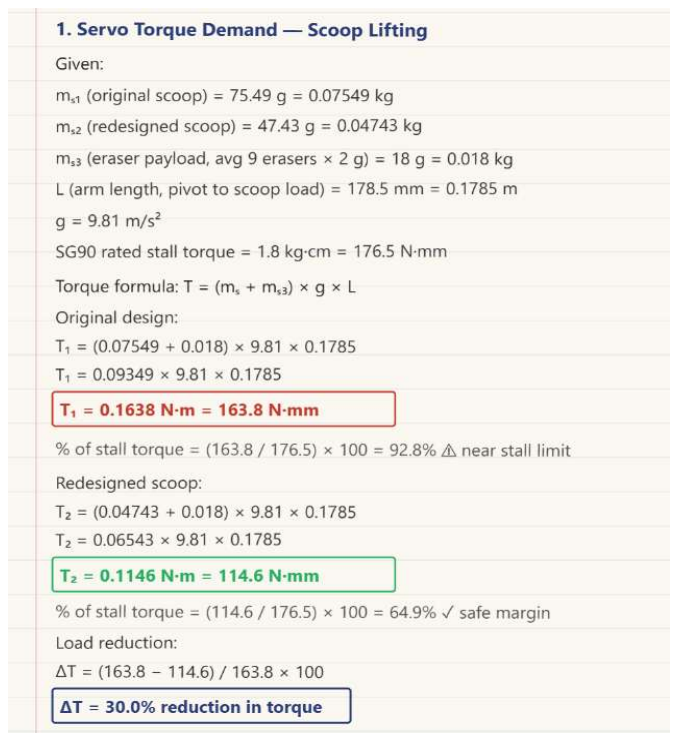
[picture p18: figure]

failure mode.

Multi-Cycle Motion Strategy

The transition from the initial single-pass coverage strategy to the final multi-cycle fan-shaped path

improved system performance in a measurable and quantifiable way. A cycle time budget was constructed

from the measured durations of each operational phase, as shown in Figure 11. Cycle 1 (straight forward pass) totalled 14,000 ms. Cycles 2 and 3 (right and left angled passes respectively) totalled 15,400 ms

each, accounting for the additional in-place turn and realignment manoeuvre. The combined estimated

robot motion time was therefore 44,800 ms (44.8 s). Across three timed full-system runs, the measured

average completion time was (87 + 87 + 83) / 3 = 85.7 seconds, comfortably within the 120-second

mission limit and providing a working margin of 34.3 seconds. The difference between the estimated

44.8s and the measured 85.7s accounts for residual eraser sorting time after robot motion was complete,

confirming that the throughput capacity of the sorting station — rather than robot travel time — was the

primary determinant of overall cycle duration. This has an important design implication: further

improvements to overall system performance would be more effectively achieved by increasing sorting

throughput than by reducing robot travel time.

Figure 11: Handwritten cycle time budget

for the three-cycle fan-shaped collection

sequence. Estimated motion time was 44.8 s,

and the measured average completion time

over 3 runs was 85.7s, leaving a 34.3s margin

within the 120 s limit. The 40.9 s difference

was due to sorting after motion ended.

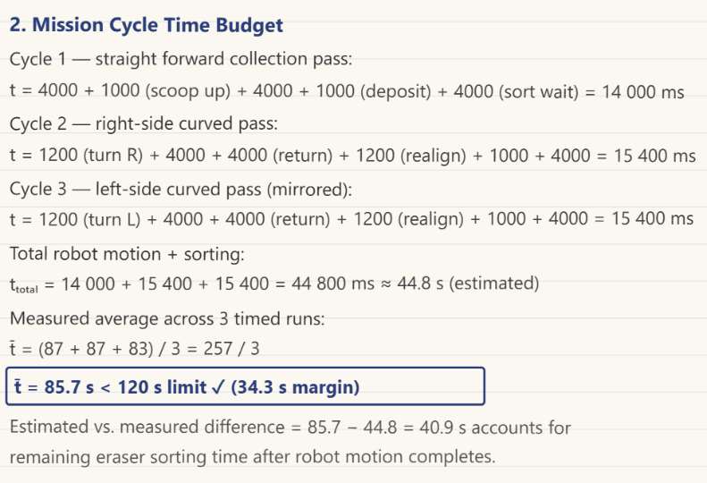
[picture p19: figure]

Overall Confidence Assessment

Confidence in the final design is assessed as moderate to high. The strongest areas are: the two-subsystem

architecture’s demonstrated ability to accommodate a complete sorting mechanism replacement without

modifying the robot; the quantitatively confirmed servo torque reduction from 92.8% to 64.9% of stall;

and empirically validated 90–92% sorting accuracy. Confidence is lower in cycle-to-cycle repeatability

because the system is sensitive to IMU zero-point drift, ultrasonic threshold, vibration intensity, and

colour-sensor thresholds — all of which shift with battery state, lighting, or reassembly. These would be

addressed in a future iteration through tighter tolerances and closed-loop feedback. Nevertheless, the iterative refinement process — spanning three chassis versions, two scoop designs, two sorting

architectures, and a navigation revision — provides clear evidence of rigorous engineering development.

### 2.4 Product Validation

Prototype validation used repeated subsystem and integrated testing to assess whether the design met its

objectives. A total of 86 runs were completed during development, with the final 12 runs using fixed code

and hardware reported here as the most representative of final performance.

Drive System and Navigation Validation

Drive system testing confirmed reliable forward motion, reversing, and turning under battery power with

all mechanisms installed. IMU heading control produced acceptable directional consistency and the robot

returned successfully to the base station across repeated trials. The V-shaped alignment walls

compensated for small heading errors during approach. The rear-wheel-drive layout and IMU navigation

strategy were confirmed sufficient for the arena conditions.

Collection Subsystem Validation

Collection testing confirmed that the original scoop geometry caused servo stall under load. Following the

chassis and scoop redesigns, reducing torque demand from 92.8% to 64.9% of stall, lifting performance

improved substantially and the robot deposited erasers consistently across trials. The tapered scoop also

improved transfer alignment with the sorting station entry, reducing misaligned deposits.

Sorting Station Validation

Sorting station validation confirmed that excessive vibration amplitude or poor track geometry caused

multiple erasers to arrive simultaneously. Iterative adjustment of motor speed and track angle improved

single-object presentation. TCS34725 threshold values were established through calibration trials with

both eraser types under representative lighting conditions, with the RGB ratio threshold set to maximise

discrimination margin. These thresholds were applied consistently across all validation runs.

Integrated System Validation

Integrated testing confirmed that the robot and sorting station executed the complete operational sequence

— collection, return, unloading, and classification — as one coordinated process. Across the 12 final runs,

the system collected an average of 15–17 erasers per sequence, returned from Cycle 1 in all 12 runs,

Cycle 2 in 10 of 12, and Cycle 3 in 8 of 12. The sorting station correctly classified green erasers in 11 of

12 runs; the single misclassification occurred when a green eraser immediately followed a non-target,

producing a mixed reading. Isolated failures were caused by erasers lodging at the hopper entry or minor

floor-drift. The system completed the task within 120 s in all 12 runs at an average of 85.7 s.

Table 4: Robot subsystem test plan and results summary.

Test objective | Method | Pass criterion | Result | Design impact
Drive forward and reverse reliably | Timed straight runs under full load | Consistent travel with no stall | Pass — consistent across all runs | Confirmed rear-wheel-drive layout sufficient
IMU heading consistency | Repeated forward passes measuring lateral drift | Drift < 15 cm over 1 m | Pass — acceptable drift for arena size | IMU calibration procedure standardised
Ultrasonic stopping accuracy | Reverse approach to station, measure stop distance | Stop within ±3 cm of target | Pass — repeatable with fixed threshold | Threshold value fixed in final code
Scoop lifting under load | Lift loaded scoop (9 erasers) 5 consecutive times | No servo stall in 5/5 attempts | Pass after redesign; failed with original scoop | Triggered scoop mass reduction and arm geometry revision
Eraser capture rate | Forward pass over 10 distributed erasers | Capture ≥ 7/10 erasers per pass | Pass — avg 8–9 per straight pass | Brush rotation speed confirmed effective
Eraser retention during reverse | Reverse 4,000 ms with loaded scoop raised | No erasers lost during transit | Pass — coordinated brush stop effective | Brush stop timing confirmed in code

Table 5: Sorting station test plan and results summary.

Test objective | Method | Pass criterion | Result | Design impact
Single-object presentation | Deposit 10 erasers, observe sensor region | ≥ 8/10 arrive individually | Pass after track angle adjustment | Track angle and vibration intensity tuned
Green eraser classification | Present 20 green erasers individually | ≥ 19/20 correctly identified | Pass — 20/20 in calibration trials | RGB threshold value fixed
Non-target rejection | Present 20 non-green erasers individually | ≥ 19/20 correctly rejected | Pass — 20/20 in calibration trials | Threshold margin confirmed adequate
Mixed-colour stream sorting | Deposit mixed batch of 10 erasers | ≥ 8/10 correctly sorted | Pass — 9/10 in mixed stream trials | One misclassification from close succession
Vibration feed continuity | Run station for 120 s continuously | No jams or feed stoppages | Pass — no mechanical stoppages observed | Vibration motor speed confirmed stable

Table 6: Integrated full-system validation results across 12 final runs using the fixed hardware and code

configuration. The system completed the task within the 120-second limit in all runs, with an average

completion time of 85.7 s.

Run | Erasers collected | Green correctly sorted | Non-targets rejected | Cycle 1 return | Cycle 2 return | Cycle 3 return | Time (s) | Notes
1 | 16 | Yes | Yes | Yes | Yes | Yes | 84 | Clean run
2 | 17 | Yes | Yes | Yes | Yes | Yes | 83 | Clean run
3 | 15 | Yes | Yes | Yes | Yes | No | 88 | Cycle 3 drift
4 | 16 | Yes | Yes | Yes | No | No | 91 | Eraser lodged at hopper
5 | 18 | Yes | Yes | Yes | Yes | Yes | 82 | Best run
6 | 14 | Partial | Yes | Yes | Yes | Yes | 87 | Green followed blue — mixed read
7 | 17 | Yes | Yes | Yes | Yes | Yes | 84 | Clean run
8 | 15 | Yes | Yes | Yes | Yes | No | 86 | Minor floor drift in Cycle 3
9 | 16 | Yes | Yes | Yes | No | No | 90 | Two erasers lodged together at entry
10 | 17 | Yes | Yes | Yes | Yes | Yes | 83 | Clean run
11 | 15 | Yes | Yes | Yes | Yes | Yes | 85 | Clean run
12 | 16 | Yes | Yes | Yes | Yes | Yes | 84 | Final validation run
Average / Summary | 16 11/12 | fully correct | 12/12 | 12/12 | 10/12 | 8/12 | 85.7 | Final fixed configuration

Figure 12: Photograph of the fully assembled autonomous scavenger

system during final validation testing, showing the mobile robot

positioned at the sorting station with the scoop in the raised deposit

position and collected erasers entering the vibratory hopper tracks of

the stationary sorting station.

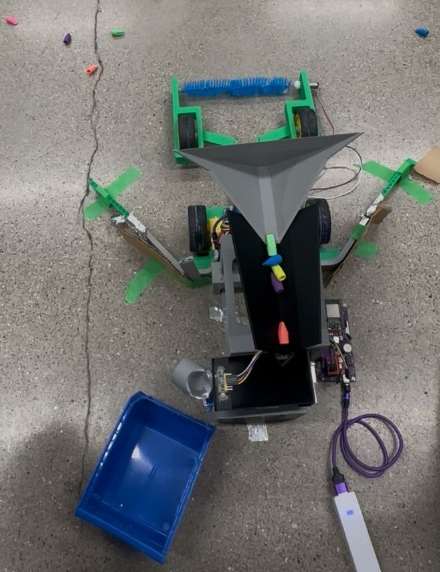
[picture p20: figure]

Validation Limitations

The primary limitations of the validation process were prototype variability and the practical constraints

of the course testing environment. The system remained sensitive to calibration-dependent parameters —

specifically IMU zero-point drift, ultrasonic stopping threshold, vibration intensity, and colour-sensor

thresholds — all of which could shift between sessions due to battery state, ambient lighting, or minor

mechanical reassembly differences. Performance also varied with the initial spatial distribution of erasers

within the arena, and the return success rate for Cycles 2 and 3 was lower than for Cycle 1, reflecting the

greater accumulated heading error over longer and angled paths. As a result, the validation results should

be interpreted as strong evidence of functional feasibility and meaningful improvement relative to earlier

prototype iterations, rather than as demonstration of production-level repeatability. Even so, the testing

programme provided clear and relevant evidence that the final design satisfied the primary project

objectives and that the implemented refinements produced consistent and measurable improvements in

collection, unloading, and sorting performance across all 12 final runs.

### 3. Conclusion

The final outcome of this project was a fully functional autonomous scavenger system composed of a

mobile collection robot and a stationary sorting subsystem at the base station. The completed design

satisfied the primary product specifications established at the start of the project: it operated autonomously using an ESP32-based control system, collected multiple erasers from an unmarked floor

area, returned to the base station without external guidance, sorted target objects from non-target objects,

and completed the full operational sequence within the required 120-second time limit. Across the final

12 validation runs, the system completed the task in an average of 85.7 s, demonstrating that the selected

architecture was feasible and effective within the given project constraints.

The two-subsystem architecture proved to be the most technically suitable solution among those

evaluated. The ability to completely replace the sorting mechanism — from rotary disc to vibratory feeder

— without modifying the mobile robot validated the modularity advantage of the selected concept. Key

iterative improvements including the skeletal chassis, redesigned scoop, connecting beam, dual vibratory

feeder, and multi-cycle fan path each produced measurable gains in reliability. These changes demonstrate

that the final solution resulted from structured engineering refinement rather than trial and error.

The final design retained identifiable limitations: sensitivity to calibration-dependent parameters, lower

return reliability for Cycles 2 and 3 due to accumulated heading error, and occasional sorting

misclassification from simultaneous eraser arrival. These indicate the prototype remains a development-

stage system with clear priorities for future refinement as described in Section 4.

### 4. Recommendations

Although the final prototype met the primary project objectives, testing identified several limitations that

should be addressed in a future design iteration to improve reliability, repeatability, and overall scoring

performance.

The first priority should be refinement of the collection mechanism. The scoop should be redesigned with

taller side walls and a continuous funnel profile to retain objects more effectively, and the gap between

the brush and scoop opening reduced, by repositioning the brush or adding a compliant rubber barrier, to prevent re-ejection. These changes would improve object retention and increase erasers delivered per

cycle.

The second priority should be improved return-path accuracy for Cycles 2 and 3. IMU-based control

alone accumulated sufficient heading error over the angled paths to reduce docking reliability.

Supplementing IMU control with encoder feedback would allow simultaneous monitoring of angular drift

and travel distance, reducing path deviation and improving base station docking consistency.

The most impactful sorting station improvement would be a single-file gating mechanism upstream of the

colour sensor. Object clustering was the primary misclassification cause and the source of the 90–92%

accuracy ceiling. A rotating escapement, timed flap, or oscillating gate — combined with a channel throat

sized to the eraser geometry — would enforce one-eraser-at-a-time presentation and significantly reduce

composite RGB readings.

The transfer geometry between the upper funnel and sensing chute should also be refined. Abrupt

transitions promoted eraser overlap when large deposits were received. A smoother guided ramp with

reduced drop height and better lateral constraint would dissipate momentum more gradually and improve

spacing consistency before classification.

Finally, the base station should be made resistant to vibratory drift. A weighted base plate, wider footprint,

or high-friction elastomeric pads would eliminate the unwanted station movement observed during

operation and improve robot-to-station alignment consistency.

These five recommendations address the most significant remaining limitations: object loss during

collection, return-path drift, multi-object sensing interference, abrupt sorter transitions, and base station

instability. Implementing them in a future iteration would meaningfully improve collection reliability,

sorting accuracy, and overall system robustness.

References

[1] G. Bose, “Coral: Teachable Sorter,” Google Coral, Nov. 2019. [Online]. Available:

https://www.coral.ai/projects/teachable-sorter/

[2] Electronoobs, “Object colour sorter with servo and Arduino,” YouTube, 2021. [Online]. Available:

https://youtu.be/H7HTQai7Wwg

[3] RaspberryPi Foundation, “Sorting machine with camera,” YouTube, 2022. [Online]. Available:

https://youtu.be/r78rIRVYsgY

[4] TAOS Inc., “TCS3472 Colour Light-to-Digital Converter Datasheet,” ams-OSRAM, 2012. [Online].

Available: https://ams.com/tcs34725

[5] InvenSense, “MPU-9255 9-Axis MotionTracking Device Datasheet,” TDK, 2015. [Online]. Available:

https://invensense.tdk.com

[6] TowerPro, “SG90 9 g Micro Servo Motor Datasheet,” [Online]. Available:

https://components101.com/sites/default/files/component_datasheet/SG90%20Servo%20Motor%20Datas

heet.pdf

[7] Elecfreaks, “HC-SR04 Ultrasonic Ranging Module Datasheet,” [Online]. Available:

https://cdn.sparkfun.com/datasheets/Sensors/Proximity/HCSR04.pdf

[8] ams-OSRAM, “TCS34725 Color Light-to-Digital Converter Datasheet,” [Online]. Available:

https://cdn-shop.adafruit.com/datasheets/TCS34725.pdf

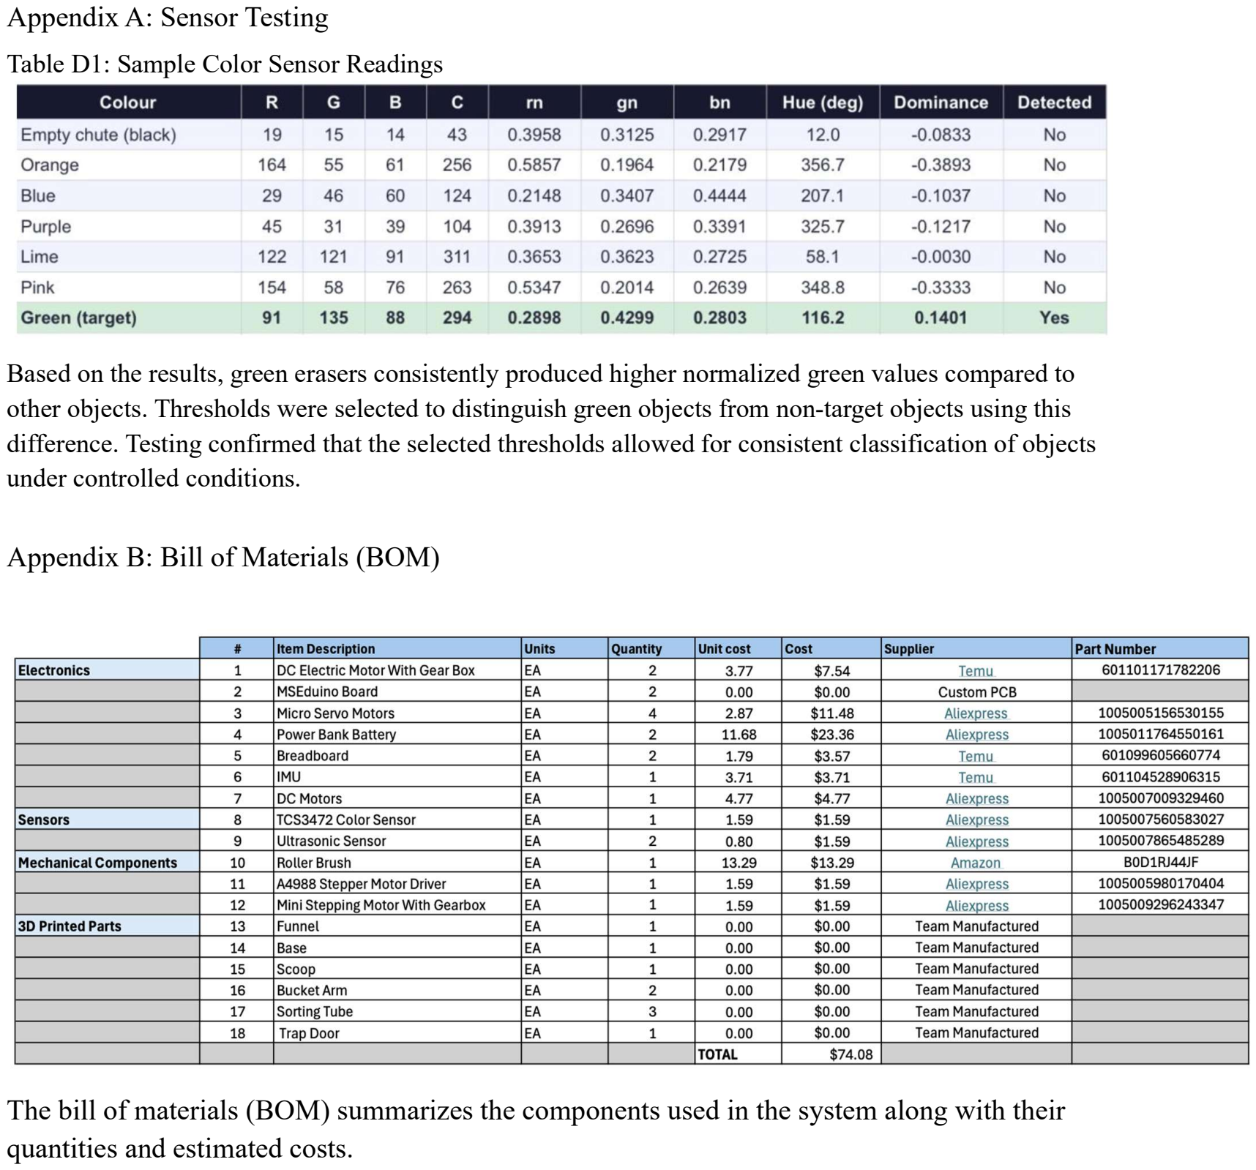
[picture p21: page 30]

Appendix A: Sensor Testing
Table D1: Sample Color Sensor Readings

Based on the results, green erasers consistently produced higher normalized green values compared to other objects. Thresholds were selected to distinguish green objects from non-target objects using this difference. Testing confirmed that the selected thresholds allowed for consistent classification of objects under controlled conditions.

Appendix B: Bill of Materials (BOM)

The bill of materials (BOM) summarizes the components used in the system along with their quantities and estimated costs.

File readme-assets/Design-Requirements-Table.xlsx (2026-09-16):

Category | Requirement | Value / Target | Justification
Operation | Autonomous operation | Fully autonomous (no remote control) | Required by project constraints
Time | Task completion time | ≤ 120 s | Competition constraint
Navigation | Heading control | IMU-based orientation tracking | Accurate turning and alignment
 | Positioning | Ultrasonic distance sensing | Controlled return to base
 | Return-to-base accuracy | Reliable alignment with base station | Ensures successful object deposition
Collection | Collection mechanism | Rotary brush + scoop | Continuous object pickup
 | Object retention | Scoop retains objects during reverse | Prevent loss
Mechanical | Drive system | Rear-wheel drive + support wheels | Stability and control
 | Structure | Lightweight 3D printed chassis | Reduces overall system weight and actuator load
 | Scoop actuation | Servo lifting mechanism | Controlled dumping
 | Robot weight | Minimized within structural limits | Reduces motor load and improves efficiency
Sorting | Sorting method | Stationary system at base | Better accuracy
 | Classification | Color sensor detection | Green vs non-green
 | Accuracy | ≥ 90% | Ensures accurate classification and maximizes scoring performance
 | Object flow | Vibration mechanism | Prevent clogging
 | Alignment | Rail-guided positioning | Accurate drop-off
Control | System logic | State-based control | Structured operation
Power | Power source | Onboard battery | Mobility
Constraints | Robot size | Within competition limits | Must physically fit within arena and comply with rules
 | Sensor limits | Limited detection time | Requires controlled object flow for accurate detection
Enviroment | Operating area | ~15 m² flat surface, no guides | Requires autonomous navigation

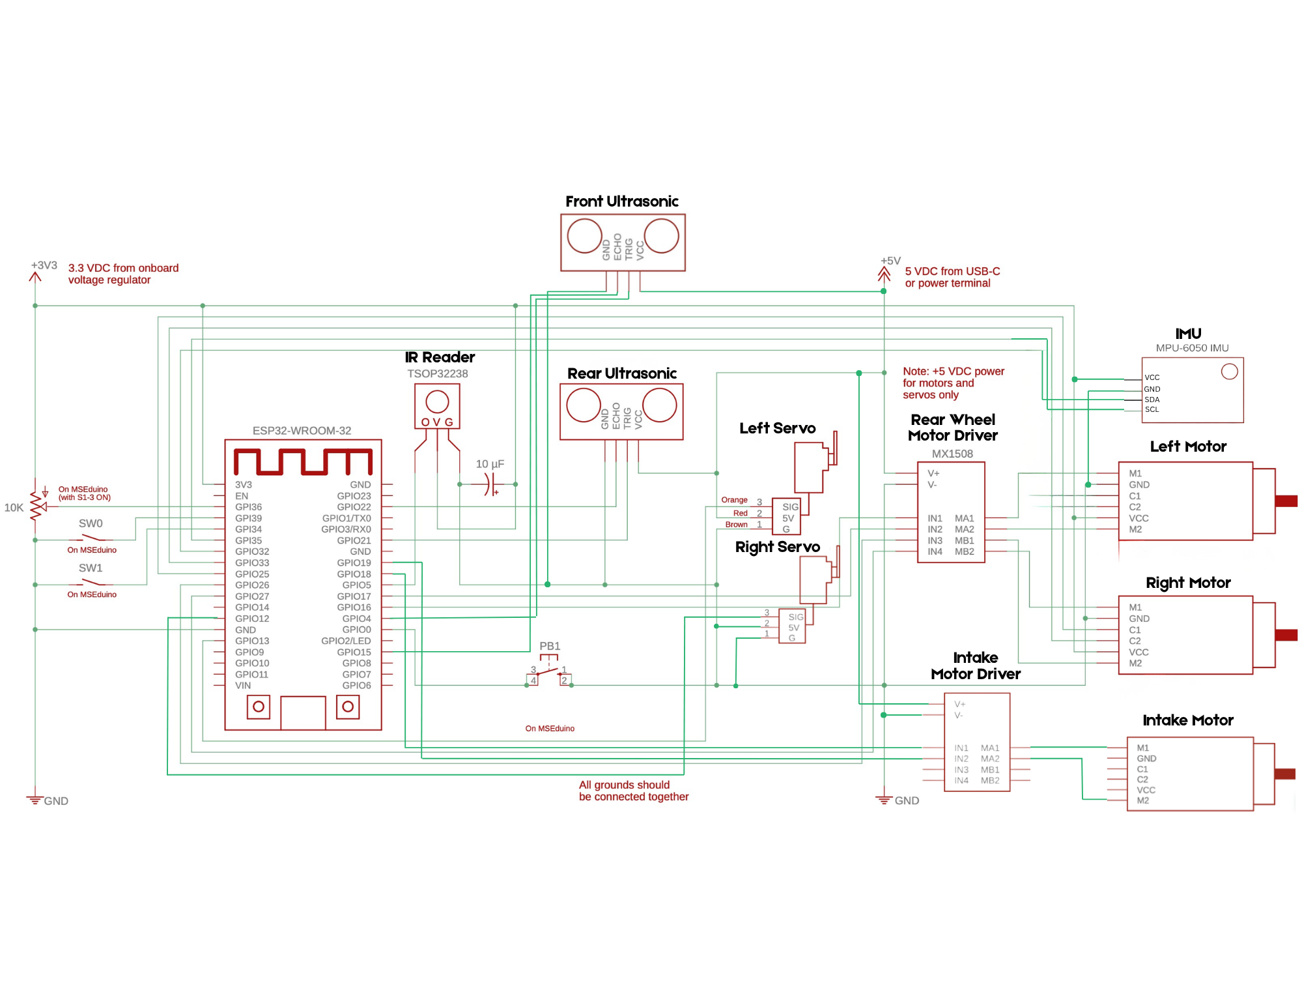
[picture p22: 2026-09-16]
Final Code and Electrical/Electrical References/Scavenger Circuit Schematic.png

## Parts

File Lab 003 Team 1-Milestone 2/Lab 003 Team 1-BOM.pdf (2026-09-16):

# | Item Description | Units | Quantity | Unit cost | Cost | Supplier | Part Number

Electronics | 1 | DC Electric Motor With Gear Box | EA | 2 | 3.77 | $7.54 | Temu (https://www.temu.com/ca/electric-motor-3-6v-dual-shaft-tt-magnetic-gearbox-engine-with-4pcs-plastic-car-tire-wheel-for-four-wheel-drive-car-robotic-body-aircr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) | 601101171782206
| 2 | MSEduino Board | EA | 2 | 0.00 | $0.00 | Custom PCB
| 3 | Micro Servo Motors | EA | 4 | 2.87 | $11.48 | Aliexpress (https://www.aliexpress.com/item/1005005156530155.html) | 1005005156530155
| 4 | Power Bank Battery | EA | 2 | 11.68 | $23.36 | Aliexpress (https://www.aliexpress.com/item/1005011764550161.html) | 1005011764550161
| 5 | Breadboard | EA | 2 | 1.79 | $3.57 | Temu (https://www.temu.com/ca/1pc-2pcs-400-830-hole-large-breadboard-line-mb-102-electronic-diy-circuit-board-breadboard-kit-g-601099605660774.html) | 601099605660774
| 6 | IMU | EA | 1 | 3.71 | $3.71 | Temu (https://www.temu.com/ca/compatible-for-mpu-9250-6500-9-dof-imu-sensor-module-gy-6500-g-6011045289063158.html) | 601104528906315
| 7 | DC Motors | EA | 1 | 4.77 | $4.77 | Aliexpress (https://www.aliexpress.com/item/1005007009329460.html) | 1005007009329460
Sensors | 8 | TCS3472 Color Sensor | EA | 1 | 1.59 | $1.59 | Aliexpress (https://www.aliexpress.com/item/1005007560583027.html) | 1005007560583027
| 9 | Ultrasonic Sensor | EA | 2 | 0.80 | $1.59 | Aliexpress (https://www.aliexpress.com/item/1005007865485289.html) | 1005007865485289
Mechanical Components | 10 | Roller Brush | EA | 1 | 13.29 | $13.29 | Amazon (https://www.amazon.ca/dp/B0D1RJ44JF) | B0D1RJ44JF
| 11 | A4988 Stepper Motor Driver | EA | 1 | 1.59 | $1.59 | Aliexpress (https://www.aliexpress.com/item/1005005980170404.html) | 1005005980170404
| 12 | Mini Stepping Motor With Gearbox | EA | 1 | 1.59 | $1.59 | Aliexpress (https://www.aliexpress.com/item/1005009296243347.html) | 1005009296243347
3D Printed Parts | 13 | Funnel | EA | 1 | 0.00 | $0.00 | Team Manufactured
| 14 | Base | EA | 1 | 0.00 | $0.00 | Team Manufactured
| 15 | Scoop | EA | 1 | 0.00 | $0.00 | Team Manufactured
| 16 | Bucket Arm | EA | 2 | 0.00 | $0.00 | Team Manufactured
| 17 | Sorting Tube | EA | 3 | 0.00 | $0.00 | Team Manufactured
| 18 | Trap Door | EA | 1 | 0.00 | $0.00 | Team Manufactured
| | | | | TOTAL | $74.08

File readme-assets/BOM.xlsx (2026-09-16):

 | # | Item Description | Units | Quantity | Unit cost | Cost | Supplier | Part Number
Electronics | 1 | DC Electric Motor With Gear Box | EA | 2 | $3.77 | $7.54 | Temu (https://www.temu.com/ca/electric-motor-3-6v-dual-shaft-tt-magnetic-gearbox-engine-with-4pcs-plastic-car-tire-wheel-for-four-wheel-drive-car-robotic-body-aircr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) | 601101171782206
 | 2 | MSEduino Board | EA | 2 | $0.00 | $0.00 | Custom PCB
 | 3 | Micro Servo Motors | EA | 5 | $2.30 | $11.48 | Aliexpress (https://www.aliexpress.com/item/1005005156530155.html) | 1005005156530155
 | 4 | Power Bank Battery | EA | 2 | $11.68 | $23.36 | Aliexpress (https://www.aliexpress.com/item/1005011764550161.html) | 1005011764550161
 | 5 | Breadboard | EA | 2 | $1.79 | $3.57 | Temu (https://www.temu.com/ca/1pc-2pcs-400-830-hole-large-breadboard-line-mb-102-electronic-diy-circuit-board-breadboard-kit-g-601099605660774.html) | 601099605660774
 | 6 | IMU | EA | 1 | $3.71 | $3.71 | Temu (https://www.temu.com/ca/compatible-for-mpu-9250-6500-9-dof-imu-sensor-module-gy-6500-g-6011045289063158.html) | 601104528906315
 | 7 | DC Motors | EA | 1 | $4.77 | $4.77 | Aliexpress (https://www.aliexpress.com/item/1005007009329460.html) | 1005007009329460
 | 8 | Motor with encoders | EA | 2 | $12.74 | $25.49 | Amazon (https://www.amazon.ca/uxcell%C2%AE-GA12-N20-Encoder-Velocity-Measurement/dp/B07N1FG61K?hvadid=80127111503462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) | B07N1FG61K
Sensors | 9 | TCS3472 Color Sensor | EA | 1 | $1.59 | $1.59 | Aliexpress (https://www.aliexpress.com/item/1005007560583027.html) | 1005007560583027
 | 10 | Ultrasonic Sensor | EA | 2 | $0.80 | $1.59 | Aliexpress (https://www.aliexpress.com/item/1005007865485289.html) | 1005007865485289
Mechanical Components | 11 | Roller Brush | EA | 1 | $13.29 | $13.29 | Amazon (https://www.amazon.ca/dp/B0D1RJ44JF) | B0D1RJ44JF
 | 12 | Wheels | EA | 4 | $3.77 | $7.54 | Temu (https://www.temu.com/ca/electric-motor-3-6v-dual-shaft-tt-magnetic-gearbox-engine-with-4pcs-plastic-car-tire-wheel-for-four-wheel-drive-car-robotic-body-aircr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) | 601101171782206
3D Printed Parts: Filament: 500 g (bamboo labs PLA Basic) | 13 | Funnel | EA | 1 | $0.00 | $0.00 | Team Manufactured | 601101171782206
 | 14 | Base/Chassis | EA | 1 | $0.00 | $0.00 | Team Manufactured
 | 15 | Scoop | EA | 1 | $0.00 | $0.00 | Team Manufactured
 | 16 | Bucket Arm | EA | 2 | $0.00 | $0.00 | Team Manufactured
 | 17 | Sorting Tube | EA | 3 | $0.00 | $0.00 | Team Manufactured
 | 18 | Trap Door | EA | 1 | $0.00 | $0.00 | Team Manufactured
 | 19 | Front wheel axles | EA | 2 | $0.00 | $0.00 | Team Manufactured
 |  |  |  |  | TOTAL | $103.93

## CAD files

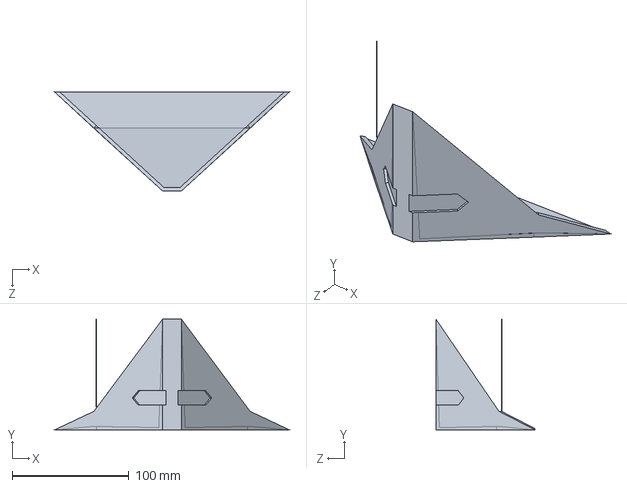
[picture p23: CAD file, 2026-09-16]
Final CADs and Drawings/Scavenger CADs/Scooping Mechanism.SLDPRT
201.4 x 95.0 x 85.0 mm

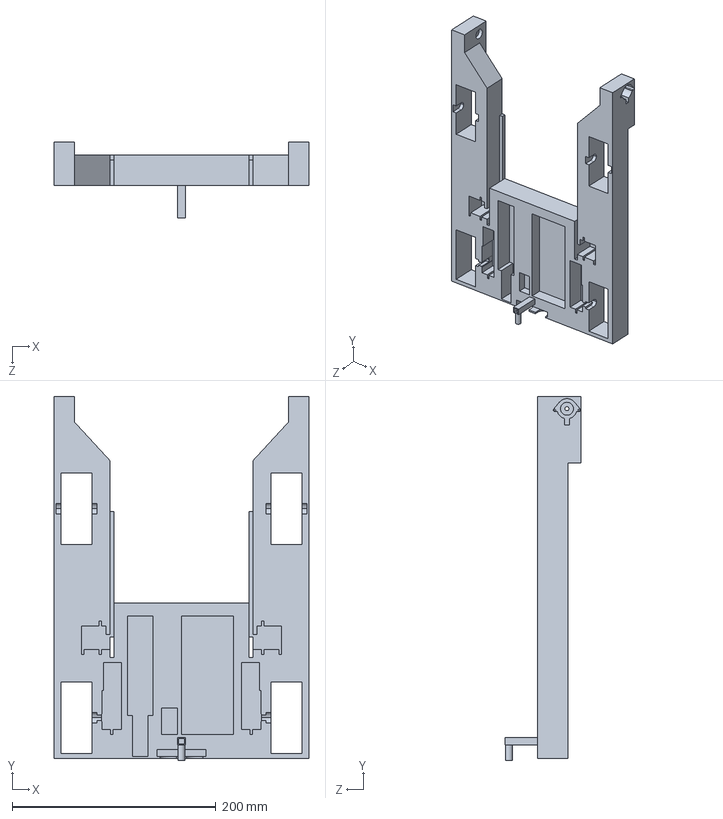
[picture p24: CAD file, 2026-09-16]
Lab 003 Team 1-Milestone 2/Bot/Solidworks/Base and Chasis.SLDPRT
250.0 x 357.0 x 75.0 mm

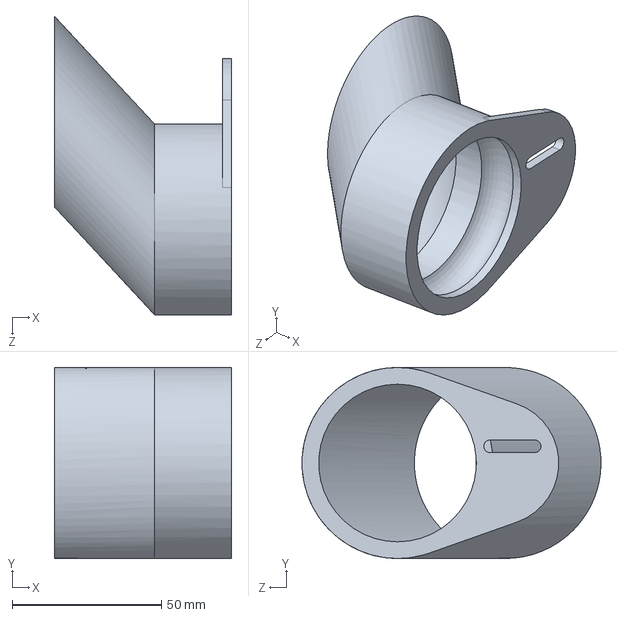
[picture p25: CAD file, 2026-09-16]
Lab 003 Team 1-Milestone 2/Sorting System/Solidworks Files/Bearing/Save Bodies2[12].SLDPRT
59.4 x 64.0 x 100.1 mm

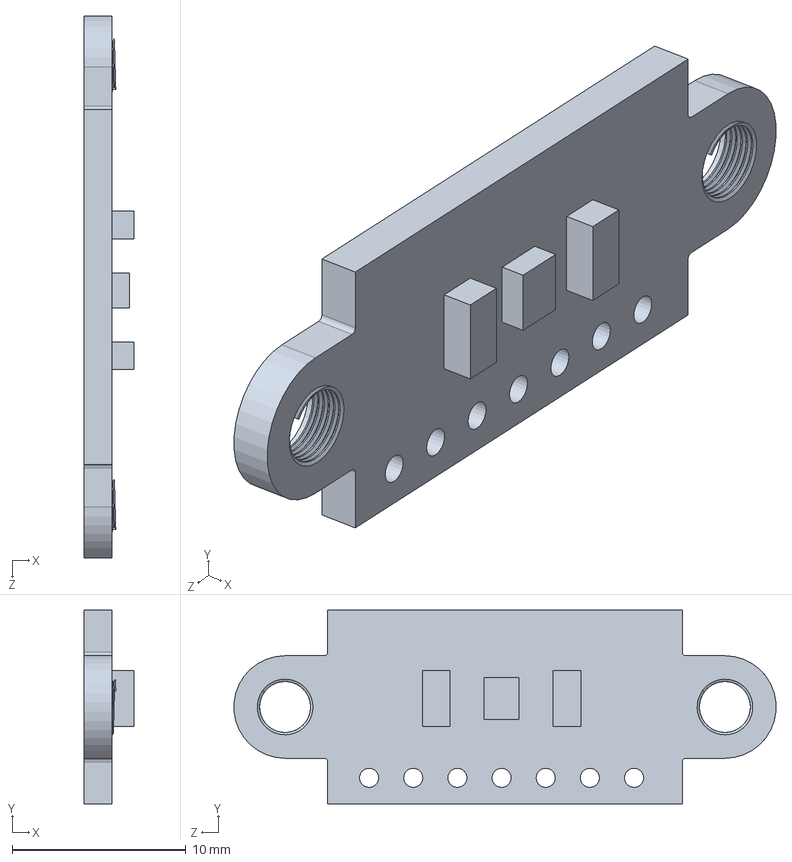
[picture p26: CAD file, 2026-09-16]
Lab 003 Team 1-Milestone 2/Sorting System/Solidworks Files/BlastGate/TCS3472.SLDPRT
2.85 x 11.1 x 31.2 mm

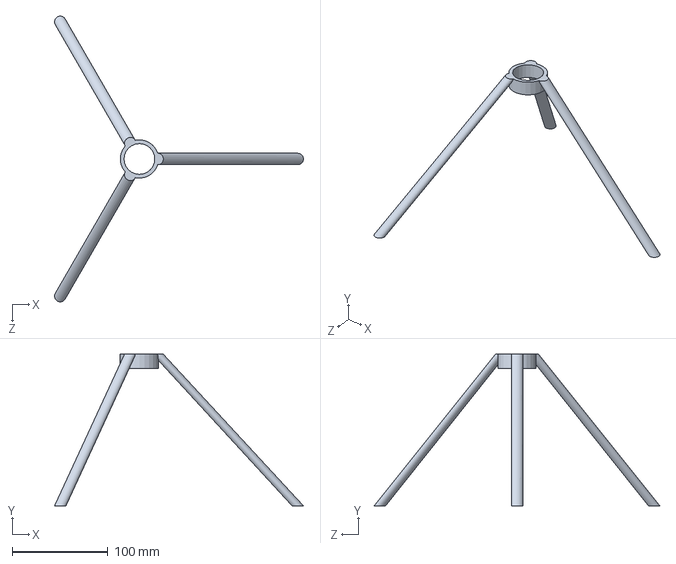
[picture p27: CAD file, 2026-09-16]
Lab 003 Team 1-Milestone 2/Sorting System/Solidworks Files/Mount/Mount.SLDPRT
259.5 x 158.0 x 297.8 mm

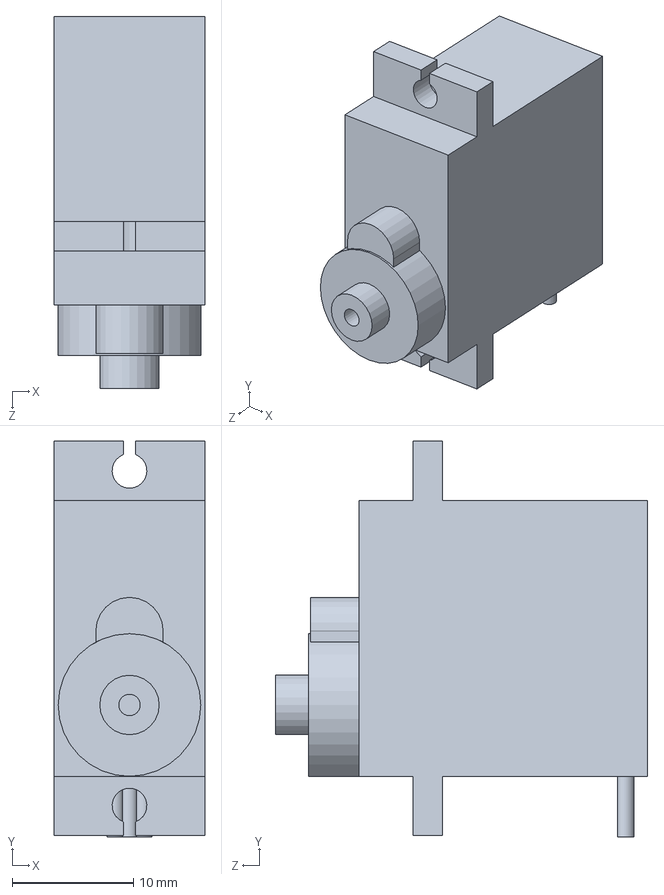
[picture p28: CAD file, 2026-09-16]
Lab 003 Team 1-Milestone 2/Sorting System/Solidworks Files/Servo/servo 25.SLDPRT
12.4 x 32.6 x 30.6 mm

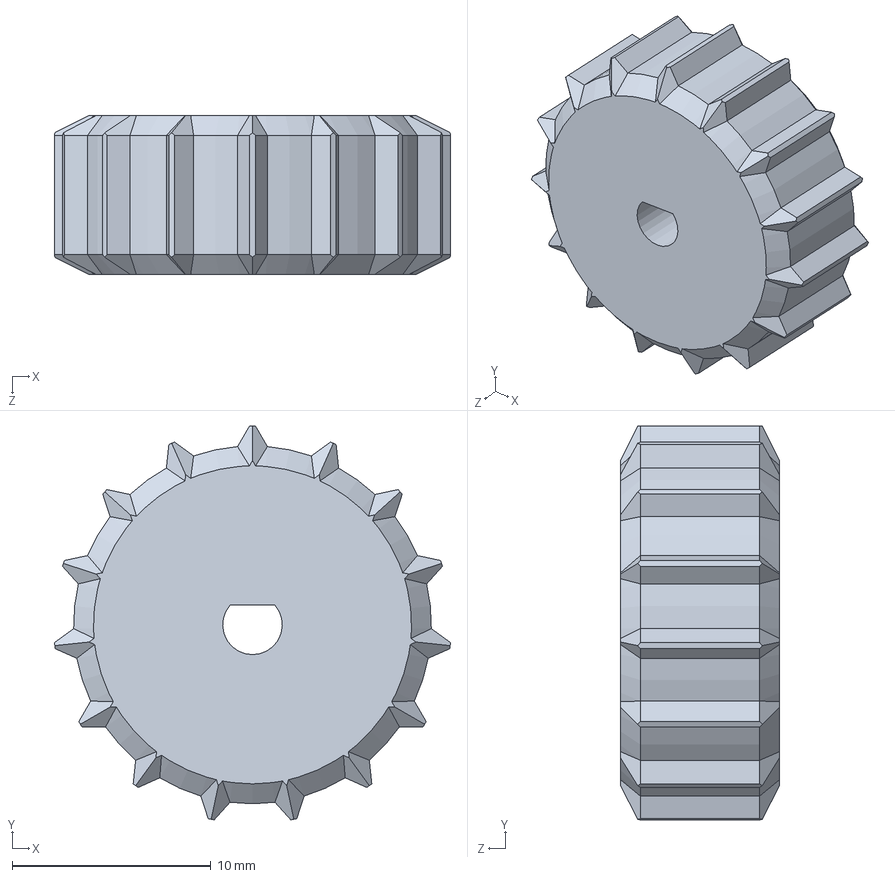
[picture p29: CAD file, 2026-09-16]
Lab 003 Team 1-Milestone 2/Sorting System/Solidworks Files/Sorting Wheel/Part4.SLDPRT
19.9 x 19.8 x 8.00 mm

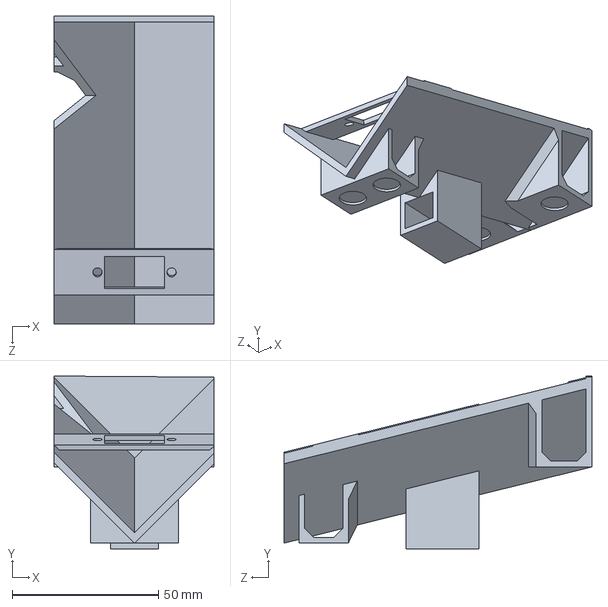
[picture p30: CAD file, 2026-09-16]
Milestone 4_Sorting and Collecting/Sorter Cads/V2 1.sldprt
54.6 x 59.0 x 105.0 mm

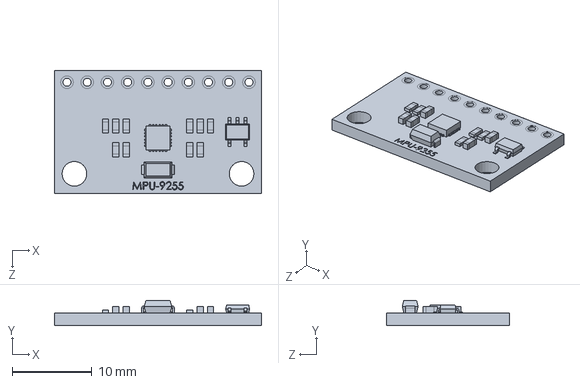
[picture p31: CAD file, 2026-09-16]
Lab 003 Team 1-Milestone 2/Bot/Solidworks/IMU.SLDPRT
26.0 x 3.20 x 15.5 mm

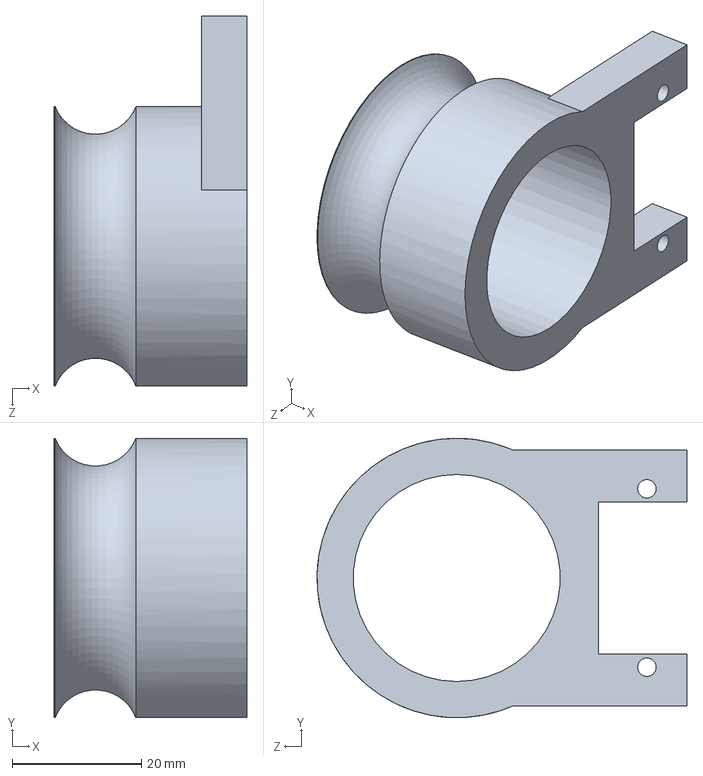
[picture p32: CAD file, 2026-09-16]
Lab 003 Team 1-Milestone 2/Sorting System/Solidworks Files/Bearing/ball4.SLDPRT
29.8 x 43.2 x 57.2 mm

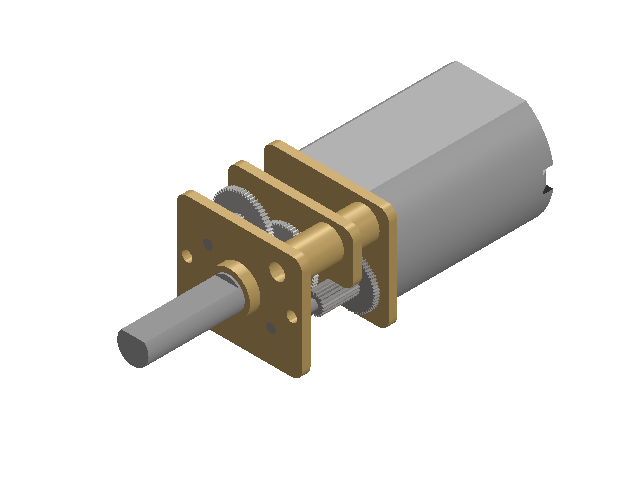
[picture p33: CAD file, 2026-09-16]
Lab 003 Team 1-Milestone 2/Sorting System/Solidworks Files/Indexer/N20 DC Gear Motor.SLDASM
Gear Box.step
Shaft.step
Motor.step

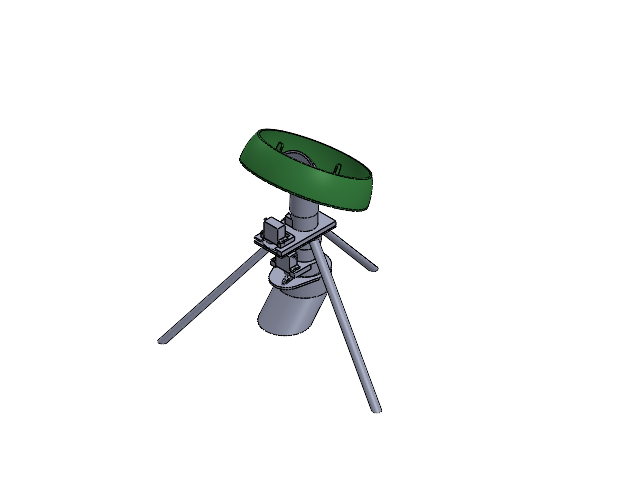
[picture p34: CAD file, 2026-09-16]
Lab 003 Team 1-Milestone 2/Sorting System/Solidworks Files/Main Assembily/Main Assembily.SLDASM
Gear Box.step
Shaft.step
Motor.step
Part2 better
bottom
plate
TCS3472
top
MG90S horn
pin
servo 25 x 2
ball1 x 12
Save Bodies2[12]
ball4
Mount

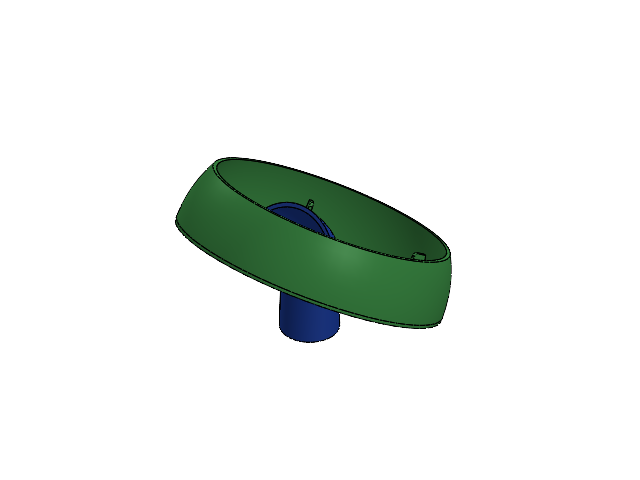
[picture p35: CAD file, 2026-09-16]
Lab 003 Team 1-Milestone 2/Sorting System/Solidworks Files/Sorting Wheel/Assem1.SLDASM
Part2 better
Gear Box.step
Shaft.step
Motor.step

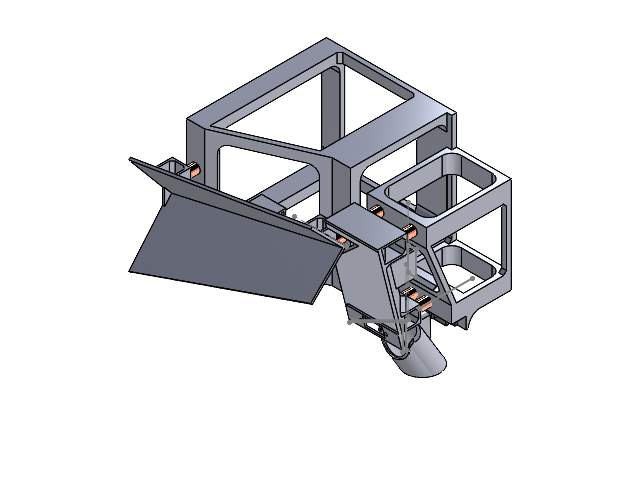
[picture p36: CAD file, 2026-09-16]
Final CADs and Drawings/Sorter CADs/Assem1.SLDASM
V1 MOUNT
V2 1
V2 MOUNT
Spring Cylinder x 8
V1 1
servo 25
Chute

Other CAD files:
Lab 003 Team 1-Milestone 2/Sorting System/Solidworks Files/Sorting Wheel/N20 DC Gear Motor.SLDASM
Milestone 4_Sorting and Collecting/Sorter Cads/Assem1.SLDASM
Final CADs and Drawings/Scavenger CADs/ServoMotor.SLDPRT
Final CADs and Drawings/Sorter CADs/V2 1.sldprt
Final CADs and Drawings/Engineering Drawings/Battery Clips.SLDDRW
Final CADs and Drawings/Engineering Drawings/Chasis.SLDDRW
Final CADs and Drawings/Engineering Drawings/Chute.SLDDRW
Final CADs and Drawings/Engineering Drawings/Scoop Arm.SLDDRW
Final CADs and Drawings/Engineering Drawings/Scooping Mechanism.SLDDRW
Final CADs and Drawings/Engineering Drawings/V1 MOUNT.SLDDRW
Final CADs and Drawings/Engineering Drawings/V1.SLDDRW
Final CADs and Drawings/Engineering Drawings/V2 MOUNT.SLDDRW
Final CADs and Drawings/Engineering Drawings/V2.SLDDRW
Final CADs and Drawings/Scavenger CADs/Battery Clips.SLDPRT
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

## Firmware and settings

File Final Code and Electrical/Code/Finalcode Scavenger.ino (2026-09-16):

#include <Arduino.h>
#include <Adafruit_NeoPixel.h>

// Function declarations
void doHeartbeat();
void setMotor(int dir, int pwm, int in1, int in2);
void setIntakeMotor(int dir, int pwm);
void initUltrasonic(struct Ultrasonic* us);
void ping(struct Ultrasonic* us);
uint32_t getEchoTime(struct Ultrasonic* us);
uint32_t usToCm(uint32_t us);
uint32_t usToIn(uint32_t us);
uint32_t angleToDuty(int angle);
void writeServos(int leftAngle, int rightAngle);
void setServosHome();
void ARDUINO_ISR_ATTR usTimerISR(void* arg);
void ARDUINO_ISR_ATTR echoISR(void* arg);

// Ultrasonic sensor structure
struct Ultrasonic {
  const int triggerPin;
  const int echoPin;
  volatile uint32_t pulseBegin = 0;
  volatile uint32_t pulseEnd = 0;
  volatile bool newEcho = false;
  volatile bool timeout = false;
  hw_timer_t* pTimer = NULL;
};

// Constants
const int cHeartbeatInterval = 75;
const int cSmartLED = 23;
const int cSmartLEDCount = 1;

const int cIN1Pin[] = { 26, 16 };
const int cIN2Pin[] = { 27, 17 };
const int cPWMFreq = 20000;
const int cPWMRes = 8;
const int cPotPin = 36;
const int cMinPWM = 150;
const int cMaxPWM = 255;

const int cLeftServoPin = 13;
const int cRightServoPin = 12;
const int cLeftServoHome = 50;    // Left Servo's Initial Position At 0 Degrees On The Chassis
const int cRightServoHome = 110;  // Right Servo's Initial Position At 0 Degrees On The Chassis

const int cIntakeIN1 = 18;   // IN1 Pin For Intake Motor's Motor Driver
const int cIntakeIN2 = 19;   // IN2 Pin For Intake Motor's Motor Driver
const int cIntakePWM = 250;  // Speed Of The Intake Motor

const int cTrigger = 11;
const int cMaxEcho = 15000;
const uint32_t cUSStopCm = 15;  // Distance The Ultrasonic Reads To Stop

const int cMotorAdjustment[] = { 0, -5 };  // Motor Adjustment For More Equal And Straight Driving
const uint32_t cForwardTimeMs = 4000;      // Forward Drive Time, Tuned To Cover The Collection Path
const uint32_t cTurnTimeMs = 1400;         // Turn Time Tuned For The Angled Collection Paths
const uint32_t cServoStepMs = 25;
const int cServoSteps = 110;  // Tuned To Get To The Right Angle When Scoop Is Lifted To The Sorter Hopper

const int cMidLiftDeg = 50;                  // Midlift To Keep The Erasers From Falling When Reversing
const uint32_t cPostStopAlignMs = 5000;     // Additional Driving Delay For The Scavenger To Align With The Base Station Using The Guiding Arms/Rails

// Variables
boolean timeUp6sec = false;
boolean timeUp2sec = false;
uint32_t timerCount6sec = 0;
uint32_t timerCount2sec = 0;
uint32_t lastTime = 0;
uint32_t lastHeartbeat = 0;

uint8_t driveSpeed = 0;
uint8_t driveIndex = 0;
uint8_t robotModeIndex = 2;

Ultrasonic ultrasonic = { 21, 22 };
uint32_t lastPulse = 0;
uint32_t cycles = 0;
uint32_t stateStartMs = 0;
uint32_t servoStepStartMs = 0;
int servoStepIndex = 0;

// Smart LED
Adafruit_NeoPixel SmartLEDs(cSmartLEDCount, cSmartLED, NEO_RGB + NEO_KHZ800);

unsigned char LEDBrightnessIndex = 0;
unsigned char LEDBrightnessLevels[] = { 0, 0, 0, 5, 15, 30, 45, 60, 75, 90, 105, 120, 135,
                                        150, 135, 120, 105, 90, 75, 60, 45, 30, 15, 5, 0 };

uint32_t modeIndicator[3] = {
  SmartLEDs.Color(255, 0, 0),
  SmartLEDs.Color(0, 255, 0),
  SmartLEDs.Color(0, 0, 255)
};

void setup() {
  Serial.begin(115200);

  SmartLEDs.begin();
  SmartLEDs.clear();
  SmartLEDs.setPixelColor(0, SmartLEDs.Color(0, 0, 0));
  SmartLEDs.setBrightness(0);
  SmartLEDs.show();

  for (int k = 0; k < 2; k++) {
    ledcAttach(cIN1Pin[k], cPWMFreq, cPWMRes);
    ledcAttach(cIN2Pin[k], cPWMFreq, cPWMRes);
  }

  ledcAttach(cIntakeIN1, cPWMFreq, cPWMRes);
  ledcAttach(cIntakeIN2, cPWMFreq, cPWMRes);

  pinMode(cLeftServoPin, OUTPUT);
  pinMode(cRightServoPin, OUTPUT);
  ledcAttach(cLeftServoPin, 50, 14);
  ledcAttach(cRightServoPin, 50, 14);

  pinMode(cPotPin, INPUT);

  initUltrasonic(&ultrasonic);

  setMotor(0, 0, cIN1Pin[0], cIN2Pin[0]);
  setMotor(0, 0, cIN1Pin[1], cIN2Pin[1]);
  setIntakeMotor(0, 0);
  setServosHome();
}

void loop() {
  int pot = 0;
  uint32_t pulseDuration;

  uint32_t curTime = micros();
  if (curTime - lastTime > 1000) {
    lastTime = curTime;

    timerCount6sec += 1;
    if (timerCount6sec > 6000) {
      timerCount6sec = 0;
      timeUp6sec = true;
    }

    timerCount2sec += 1;
    if (timerCount2sec > 2000) {
      timerCount2sec = 0;
      timeUp2sec = true;
    }

    pot = analogRead(cPotPin);
    driveSpeed = map(pot, 0, 4095, cMinPWM, cMaxPWM);

    switch (driveIndex) {
      case 0:  // Wait 2 Seconds Before Starting
        setMotor(0, 0, cIN1Pin[0], cIN2Pin[0]);
        setMotor(0, 0, cIN1Pin[1], cIN2Pin[1]);
        setIntakeMotor(0, 0);
        setServosHome();

        if (timeUp2sec) {
          timerCount2sec = 0;
          timeUp2sec = false;
          stateStartMs = millis();
          driveIndex = 1;
        }
        break;

        // Cycle 1: FRONT SEQUENCE

      case 1:  // Drive Forward With Intake On
        setMotor(-1, driveSpeed + cMotorAdjustment[0], cIN1Pin[0], cIN2Pin[0]);
        setMotor(1, driveSpeed + cMotorAdjustment[1], cIN1Pin[1], cIN2Pin[1]);
        setIntakeMotor(-1, cIntakePWM);

        if (millis() - stateStartMs >= cForwardTimeMs) {
          setMotor(0, 0, cIN1Pin[0], cIN2Pin[0]);
          setMotor(0, 0, cIN1Pin[1], cIN2Pin[1]);
          setIntakeMotor(-1, cIntakePWM);
          servoStepStartMs = millis();
          servoStepIndex = 0;
          driveIndex = 2;
        }
        break;

      case 2:  // Pre-Lift To Stop Erasers From Falling Back Out
        setMotor(0, 0, cIN1Pin[0], cIN2Pin[0]);
        setMotor(0, 0, cIN1Pin[1], cIN2Pin[1]);
        setIntakeMotor(-1, cIntakePWM);

        if (millis() - servoStepStartMs >= cServoStepMs) {
          servoStepStartMs = millis();
          if (servoStepIndex <= cMidLiftDeg) {
            writeServos(cLeftServoHome + servoStepIndex, cRightServoHome - servoStepIndex);
            servoStepIndex++;
          } else {
            cycles = 0;
            lastPulse = 0;
            driveIndex = 3;
          }
        }
        break;

      case 3:  // Reverse Straight To Base
        setMotor(1, driveSpeed + cMotorAdjustment[0], cIN1Pin[0], cIN2Pin[0]);
        setMotor(-1, driveSpeed + cMotorAdjustment[1], cIN1Pin[1], cIN2Pin[1]);
        setIntakeMotor(-1, cIntakePWM);

        if (cycles == 0) ping(&ultrasonic);
        cycles++;
        if (cycles >= 100) cycles = 0;

        pulseDuration = getEchoTime(&ultrasonic);
        if (pulseDuration > 0) {
          lastPulse = pulseDuration;
          if (usToCm(lastPulse) <= cUSStopCm) {
            stateStartMs = millis();
            driveIndex = 4;
          }
        }
        break;

      case 4:  // Post-Stop Align To Make Sure The Scavenger Is Aligned With Base Before Drop-Off
        setMotor(1, driveSpeed + cMotorAdjustment[0], cIN1Pin[0], cIN2Pin[0]);
        setMotor(-1, driveSpeed + cMotorAdjustment[1], cIN1Pin[1], cIN2Pin[1]);
        setIntakeMotor(-1, cIntakePWM);

        if (millis() - stateStartMs >= cPostStopAlignMs) {
          setMotor(0, 0, cIN1Pin[0], cIN2Pin[0]);
          setMotor(0, 0, cIN1Pin[1], cIN2Pin[1]);
          servoStepStartMs = millis();
          servoStepIndex = cMidLiftDeg;
          driveIndex = 5;
        }
        break;

      case 5:  // Lift Rest Of Way For Drop-Off
        setMotor(0, 0, cIN1Pin[0], cIN2Pin[0]);
        setMotor(0, 0, cIN1Pin[1], cIN2Pin[1]);
        setIntakeMotor(-1, cIntakePWM);

        if (millis() - servoStepStartMs >= cServoStepMs) {
          servoStepStartMs = millis();
          if (servoStepIndex <= cServoSteps) {
            writeServos(cLeftServoHome + servoStepIndex, cRightServoHome - servoStepIndex);
            servoStepIndex++;
          } else {
            timerCount6sec = 0;
            timeUp6sec = false;
            driveIndex = 6;
          }
        }
        break;

      case 6:  // Hold Up For 6 Seconds To Make Sure The Scoop Is Empty Before Moving Off
        setMotor(0, 0, cIN1Pin[0], cIN2Pin[0]);
        setMotor(0, 0, cIN1Pin[1], cIN2Pin[1]);
        setIntakeMotor(0, 0);

        if (timeUp6sec) {
          timerCount6sec = 0;
          timeUp6sec = false;
          servoStepStartMs = millis();
          servoStepIndex = cServoSteps;
          driveIndex = 7;
        }
        break;

      case 7:  // Lower Servos Back To 0 Degrees Relative To The Chassis
        setMotor(0, 0, cIN1Pin[0], cIN2Pin[0]);
        setMotor(0, 0, cIN1Pin[1], cIN2Pin[1]);
        setIntakeMotor(0, 0);

        if (millis() - servoStepStartMs >= cServoStepMs) {
          servoStepStartMs = millis();
          if (servoStepIndex >= 0) {
            writeServos(cLeftServoHome + servoStepIndex, cRightServoHome - servoStepIndex);
            servoStepIndex--;
          } else {
            setServosHome();
            stateStartMs = millis();
            driveIndex = 8;
          }
        }
        break;

      case 8:  // Turn Right In Place At Base
        setMotor(-1, driveSpeed + cMotorAdjustment[0], cIN1Pin[0], cIN2Pin[0]);
        setMotor(-1, driveSpeed + cMotorAdjustment[1], cIN1Pin[1], cIN2Pin[1]);
        setIntakeMotor(0, 0);

        if (millis() - stateStartMs >= cTurnTimeMs) {
          setMotor(0, 0, cIN1Pin[0], cIN2Pin[0]);
          setMotor(0, 0, cIN1Pin[1], cIN2Pin[1]);
          stateStartMs = millis();
          driveIndex = 9;
        }
        break;

        // Cycle 2: RIGHT SIDE

      case 9:  // Drive Forward Straight
        setMotor(-1, driveSpeed + cMotorAdjustment[0], cIN1Pin[0], cIN2Pin[0]);
        setMotor(1, driveSpeed + cMotorAdjustment[1], cIN1Pin[1], cIN2Pin[1]);
        setIntakeMotor(-1, cIntakePWM);

        if (millis() - stateStartMs >= cForwardTimeMs) {
          setMotor(0, 0, cIN1Pin[0], cIN2Pin[0]);
          setMotor(0, 0, cIN1Pin[1], cIN2Pin[1]);
          setIntakeMotor(-1, cIntakePWM);
          servoStepStartMs = millis();
          servoStepIndex = 0;
          driveIndex = 10;
        }
        break;

      case 10:  // Pre-Lift To Stop Erasers From Falling Back Out
        setMotor(0, 0, cIN1Pin[0], cIN2Pin[0]);
        setMotor(0, 0, cIN1Pin[1], cIN2Pin[1]);
        setIntakeMotor(-1, cIntakePWM);

        if (millis() - servoStepStartMs >= cServoStepMs) {
          servoStepStartMs = millis();
          if (servoStepIndex <= cMidLiftDeg) {
            writeServos(cLeftServoHome + servoStepIndex, cRightServoHome - servoStepIndex);
            servoStepIndex++;
          } else {
            cycles = 0;
            lastPulse = 0;
            driveIndex = 11;
          }
        }
        break;

      case 11:  // Reverse Straight Back To The Base
        setMotor(1, driveSpeed + cMotorAdjustment[0], cIN1Pin[0], cIN2Pin[0]);
        setMotor(-1, driveSpeed + cMotorAdjustment[1], cIN1Pin[1], cIN2Pin[1]);
        setIntakeMotor(-1, cIntakePWM);

        if (cycles == 0) ping(&ultrasonic);
        cycles++;
        if (cycles >= 100) cycles = 0;

        pulseDuration = getEchoTime(&ultrasonic);
        if (pulseDuration > 0) {
          lastPulse = pulseDuration;
          if (usToCm(lastPulse) <= cUSStopCm) {
            stateStartMs = millis();
            driveIndex = 12;
          }
        }
        break;

      case 12:  // Turn Left In Place To Re-Align
        setMotor(1, driveSpeed + cMotorAdjustment[0], cIN1Pin[0], cIN2Pin[0]);
        setMotor(1, driveSpeed + cMotorAdjustment[1], cIN1Pin[1], cIN2Pin[1]);
        setIntakeMotor(-1, cIntakePWM);

        if (millis() - stateStartMs >= cTurnTimeMs - 200) {
          stateStartMs = millis();
          driveIndex = 13;
        }
        break;

      case 13:  // Post-Stop Align To Make Sure The Scavenger Is Aligned With Base Before Drop-Off
        setMotor(1, driveSpeed + cMotorAdjustment[0], cIN1Pin[0], cIN2Pin[0]);
        setMotor(-1, driveSpeed + cMotorAdjustment[1], cIN1Pin[1], cIN2Pin[1]);
        setIntakeMotor(-1, cIntakePWM);

        if (millis() - stateStartMs >= cPostStopAlignMs) {
          setMotor(0, 0, cIN1Pin[0], cIN2Pin[0]);
          setMotor(0, 0, cIN1Pin[1], cIN2Pin[1]);
          servoStepStartMs = millis();
          servoStepIndex = cMidLiftDeg;
          driveIndex = 14;
        }
        break;

      case 14:  // Lift Rest Of Way For Drop-Off
        setMotor(0, 0, cIN1Pin[0], cIN2Pin[0]);
        setMotor(0, 0, cIN1Pin[1], cIN2Pin[1]);
        setIntakeMotor(-1, cIntakePWM);

        if (millis() - servoStepStartMs >= cServoStepMs) {
          servoStepStartMs = millis();
          if (servoStepIndex <= cServoSteps) {
            writeServos(cLeftServoHome + servoStepIndex, cRightServoHome - servoStepIndex);
            servoStepIndex++;
          } else {
            timerCount6sec = 0;
            timeUp6sec = false;
            driveIndex = 15;
          }
        }
        break;

      case 15:  // Hold Up For 6 Seconds To Make Sure The Scoop Is Empty Before Lowering
        setMotor(0, 0, cIN1Pin[0], cIN2Pin[0]);
        setMotor(0, 0, cIN1Pin[1], cIN2Pin[1]);
        setIntakeMotor(0, 0);

        if (timeUp6sec) {
          timerCount6sec = 0;
          timeUp6sec = false;
          servoStepStartMs = millis();
          servoStepIndex = cServoSteps;
          driveIndex = 16;
        }
        break;

      case 16:  // Lower Servos Back To 0 Degrees Relative To The Chassis
        setMotor(0, 0, cIN1Pin[0], cIN2Pin[0]);
        setMotor(0, 0, cIN1Pin[1], cIN2Pin[1]);
        setIntakeMotor(0, 0);

        if (millis() - servoStepStartMs >= cServoStepMs) {
          servoStepStartMs = millis();
          if (servoStepIndex >= 0) {
            writeServos(cLeftServoHome + servoStepIndex, cRightServoHome - servoStepIndex);
            servoStepIndex--;
          } else {
            setServosHome();
            stateStartMs = millis();
            driveIndex = 17;
          }
        }
        break;

      case 17:  // Turn Left In Place At Base
        setMotor(1, driveSpeed + cMotorAdjustment[0], cIN1Pin[0], cIN2Pin[0]);
        setMotor(1, driveSpeed + cMotorAdjustment[1], cIN1Pin[1], cIN2Pin[1]);
        setIntakeMotor(0, 0);

        if (millis() - stateStartMs >= (cTurnTimeMs + 500)) {
          setMotor(0, 0, cIN1Pin[0], cIN2Pin[0]);
          setMotor(0, 0, cIN1Pin[1], cIN2Pin[1]);
          stateStartMs = millis();
          driveIndex = 18;
        }
        break;

        // Cycle 3: LEFT SIDE

      case 18:  // Drive Forward Straight With The Intake On
        setMotor(-1, driveSpeed + cMotorAdjustment[0], cIN1Pin[0], cIN2Pin[0]);
        setMotor(1, driveSpeed + cMotorAdjustment[1], cIN1Pin[1], cIN2Pin[1]);
        setIntakeMotor(-1, cIntakePWM);

        if (millis() - stateStartMs >= cForwardTimeMs) {
          setMotor(0, 0, cIN1Pin[0], cIN2Pin[0]);
          setMotor(0, 0, cIN1Pin[1], cIN2Pin[1]);
          setIntakeMotor(-1, cIntakePWM);
          servoStepStartMs = millis();
          servoStepIndex = 0;
          driveIndex = 19;
        }
        break;

      case 19:  // Pre-Lift To Stop Erasers From Falling Back Out
        setMotor(0, 0, cIN1Pin[0], cIN2Pin[0]);
        setMotor(0, 0, cIN1Pin[1], cIN2Pin[1]);
        setIntakeMotor(-1, cIntakePWM);

        if (millis() - servoStepStartMs >= cServoStepMs) {
          servoStepStartMs = millis();
          if (servoStepIndex <= cMidLiftDeg) {
            writeServos(cLeftServoHome + servoStepIndex, cRightServoHome - servoStepIndex);
            servoStepIndex++;
          } else {
            cycles = 0;
            lastPulse = 0;
            driveIndex = 20;
          }
        }
        break;

      case 20:  // Reverse Straight Back To The Base
        setMotor(1, driveSpeed + cMotorAdjustment[0], cIN1Pin[0], cIN2Pin[0]);
        setMotor(-1, driveSpeed + cMotorAdjustment[1], cIN1Pin[1], cIN2Pin[1]);
        setIntakeMotor(-1, cIntakePWM);

        if (cycles == 0) ping(&ultrasonic);
        cycles++;
        if (cycles >= 100) cycles = 0;

        pulseDuration = getEchoTime(&ultrasonic);
        if (pulseDuration > 0) {
          lastPulse = pulseDuration;
          if (usToCm(lastPulse) <= cUSStopCm) {
            stateStartMs = millis();
            driveIndex = 21;
          }
        }
        break;

      case 21:  // Turn Right In Place To Re-Align
        setMotor(-1, driveSpeed + cMotorAdjustment[0], cIN1Pin[0], cIN2Pin[0]);
        setMotor(-1, driveSpeed + cMotorAdjustment[1], cIN1Pin[1], cIN2Pin[1]);
        setIntakeMotor(-1, cIntakePWM);

        if (millis() - stateStartMs >= cTurnTimeMs) {
          stateStartMs = millis();
          driveIndex = 22;
        }
        break;

      case 22:  // Post-Stop Align To Make Sure The Scavenger Is Aligned With Base Before Drop-Off
        setMotor(1, driveSpeed + cMotorAdjustment[0], cIN1Pin[0], cIN2Pin[0]);
        setMotor(-1, driveSpeed + cMotorAdjustment[1], cIN1Pin[1], cIN2Pin[1]);
        setIntakeMotor(-1, cIntakePWM);

        if (millis() - stateStartMs >= cPostStopAlignMs) {
          setMotor(0, 0, cIN1Pin[0], cIN2Pin[0]);
          setMotor(0, 0, cIN1Pin[1], cIN2Pin[1]);
          servoStepStartMs = millis();
          servoStepIndex = cMidLiftDeg;
          driveIndex = 23;
        }
        break;

      case 23:  // Lift Rest Of Way For Drop-Off
        setMotor(0, 0, cIN1Pin[0], cIN2Pin[0]);
        setMotor(0, 0, cIN1Pin[1], cIN2Pin[1]);
        setIntakeMotor(-1, cIntakePWM);

        if (millis() - servoStepStartMs >= cServoStepMs) {
          servoStepStartMs = millis();
          if (servoStepIndex <= cServoSteps) {
            writeServos(cLeftServoHome + servoStepIndex, cRightServoHome - servoStepIndex);
            servoStepIndex++;
          } else {
            timerCount6sec = 0;
            timeUp6sec = false;
            driveIndex = 24;
          }
        }
        break;

      case 24:  // Hold Up For 6 Sec To Make Sure The Scoop Is Empty Before Lowering
        setMotor(0, 0, cIN1Pin[0], cIN2Pin[0]);
        setMotor(0, 0, cIN1Pin[1], cIN2Pin[1]);
        setIntakeMotor(0, 0);

        if (timeUp6sec) {
          timerCount6sec = 0;
          timeUp6sec = false;
          servoStepStartMs = millis();
          servoStepIndex = cServoSteps;
          driveIndex = 25;
        }
        break;

      case 25:  // Lower Servos Back To 0 Degrees Relative To The Chassis And Finish
        setMotor(0, 0, cIN1Pin[0], cIN2Pin[0]);
        setMotor(0, 0, cIN1Pin[1], cIN2Pin[1]);
        setIntakeMotor(0, 0);

        if (millis() - servoStepStartMs >= cServoStepMs) {
          servoStepStartMs = millis();
          if (servoStepIndex >= 0) {
            writeServos(cLeftServoHome + servoStepIndex, cRightServoHome - servoStepIndex);
            servoStepIndex--;
          } else {
            driveIndex = 26;
            robotModeIndex = 0;
          }
        }
        break;

      case 26:  // Finished
        setMotor(0, 0, cIN1Pin[0], cIN2Pin[0]);
        setMotor(0, 0, cIN1Pin[1], cIN2Pin[1]);
        setIntakeMotor(0, 0);
        setServosHome();
        break;
    }
  }

  doHeartbeat();
}

void doHeartbeat() {
  uint32_t curMillis = millis();
  if ((curMillis - lastHeartbeat) > cHeartbeatInterval) {
    lastHeartbeat = curMillis;
    LEDBrightnessIndex++;
    if (LEDBrightnessIndex >= sizeof(LEDBrightnessLevels)) {
      LEDBrightnessIndex = 0;
    }
    SmartLEDs.setBrightness(LEDBrightnessLevels[LEDBrightnessIndex]);
    SmartLEDs.setPixelColor(0, modeIndicator[robotModeIndex]);
    SmartLEDs.show();
  }
}

void setMotor(int dir, int pwm, int in1, int in2) {
  if (dir == 1) {
    ledcWrite(in1, pwm);
    ledcWrite(in2, 0);
  } else if (dir == -1) {
    ledcWrite(in1, 0);
    ledcWrite(in2, pwm);
  } else {
    ledcWrite(in1, 0);
    ledcWrite(in2, 0);
  }
}

void setIntakeMotor(int dir, int pwm) {
  if (dir == 1) {
    ledcWrite(cIntakeIN1, pwm);
    ledcWrite(cIntakeIN2, 0);
  } else if (dir == -1) {
    ledcWrite(cIntakeIN1, 0);
    ledcWrite(cIntakeIN2, pwm);
  } else {
    ledcWrite(cIntakeIN1, 0);
    ledcWrite(cIntakeIN2, 0);
  }
}

void initUltrasonic(Ultrasonic* us) {
  pinMode(us->triggerPin, OUTPUT);
  pinMode(us->echoPin, INPUT);
  attachInterruptArg(us->echoPin, echoISR, us, CHANGE);
  us->pTimer = timerBegin(1000000);
  timerAttachInterruptArg(us->pTimer, usTimerISR, us);
}

void ping(Ultrasonic* us) {
  timerRestart(us->pTimer);
  timerAlarm(us->pTimer, cTrigger, false, 0);
  digitalWrite(us->triggerPin, HIGH);
  us->timeout = false;
}

uint32_t getEchoTime(Ultrasonic* us) {
  if (us->newEcho && !us->timeout) {
    us->newEcho = false;
    return us->pulseEnd - us->pulseBegin;
  } else {
    return 0;
  }
}

uint32_t usToCm(uint32_t us) {
  return (uint32_t)(double)us * 0.01724;
}

uint32_t usToIn(uint32_t us) {
  return (uint32_t)(double)us * 0.006757;
}

uint32_t angleToDuty(int angle) {
  angle = constrain(angle, 0, 180);
  uint16_t us = map(angle, 0, 180, 500, 2500);
  return (uint32_t)((us / 20000.0f) * 16383.0f);
}

void writeServos(int leftAngle, int rightAngle) {
  ledcWrite(cLeftServoPin, angleToDuty(leftAngle));
  ledcWrite(cRightServoPin, angleToDuty(rightAngle));
}

void setServosHome() {
  ledcWrite(cLeftServoPin, angleToDuty(cLeftServoHome));
  ledcWrite(cRightServoPin, angleToDuty(cRightServoHome));
}

void ARDUINO_ISR_ATTR usTimerISR(void* arg) {
  Ultrasonic* us = static_cast<Ultrasonic*>(arg);

  if (timerRead(us->pTimer) < cTrigger + 10) {
    digitalWrite(us->triggerPin, LOW);
    timerRestart(us->pTimer);
    timerAlarm(us->pTimer, cMaxEcho, false, 0);
  } else {
    us->timeout = true;
  }
}

void ARDUINO_ISR_ATTR echoISR(void* arg) {
  Ultrasonic* us = static_cast<Ultrasonic*>(arg);

  if (digitalRead(us->echoPin)) {
    us->pulseBegin = micros();
  } else if (!us->timeout) {
    us->pulseEnd = micros();
    us->newEcho = true;
  }
}

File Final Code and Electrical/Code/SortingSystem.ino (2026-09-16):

// Sorting System Code - Final
// Lab 003, Group 001
#include <Wire.h>
#include "Adafruit_TCS34725.h"
#include <math.h>

// -------------------- Servo setup --------------------------
const int cServoPin = 4;
const long cMinDutyCycle = 400;
const long cMaxDutyCycle = 2100;

// Servo positions
const int SERVO_POS_DEFAULT = 0;    // non-green direction
const int SERVO_POS_GREEN   = 70;   // green direction

enum ServoState { SERVO_AT_DEFAULT, SERVO_MOVING_TO_GREEN, SERVO_AT_GREEN, SERVO_MOVING_TO_DEFAULT };
ServoState servoState = SERVO_AT_DEFAULT;

// Debounce timers
uint32_t greenSeenAt    = 0;
uint32_t notGreenSeenAt = 0;
bool greenConfirmed     = false;
const uint32_t CONFIRM_MS = 1000;

// -------------------- I2C pins -----------------------------
static const int SDA_PIN = 21;
static const int SCL_PIN = 22;

// -------------------- Color sensor -------------------------
Adafruit_TCS34725 tcs =
  Adafruit_TCS34725(TCS34725_INTEGRATIONTIME_50MS, TCS34725_GAIN_4X);

static const uint8_t AVG_SAMPLES = 3;
static const uint16_t LOOP_DELAY_MS = 20;

float GREEN_MIN_NORM = 0.40f;
float RED_MAX_NORM   = 0.32f;
float BLUE_MAX_NORM  = 0.32f;
float HUE_MIN_DEG    = 108.0f;
float HUE_MAX_DEG    = 145.0f;
float DOMINANCE_MIN  = 0.080f;
uint16_t CLEAR_MIN   = 120;

// -------------------- Motor setup --------------------------
const int M1_IN1 = 26;
const int M1_IN2 = 27;
const int M1_PWM = 25;
const int M2_IN1 = 14;
const int M2_IN2 = 16;
const int M2_PWM = 17;

const int PWM_FREQ = 20000;
const int PWM_RES  = 8;

const int M1_SPEED = 255;
const int M2_SPEED = 255;

const unsigned long RUN_TIME  = 500;   // how long each motor runs
const unsigned long GAP_TIME  = 0;   // pause between motors

enum MotorState { M1_RUNNING, GAP_TO_M2, M2_RUNNING, GAP_TO_M1 };
MotorState motorState = M1_RUNNING;
unsigned long motorStateStart = 0;

// -------------------- Data structure -----------------------
struct ColorReading {
  uint16_t r, g, b, c;
  float rn, gn, bn;
  float hue, sat, val;
  float dominance;
};

// -------------------- Utility functions --------------------
void rgbToHsv(float r, float g, float b, float &h, float &s, float &v) {
  float maxVal = fmaxf(r, fmaxf(g, b));
  float minVal = fminf(r, fminf(g, b));
  float delta = maxVal - minVal;
  v = maxVal;
  if (maxVal <= 0.0f) { s = 0.0f; h = 0.0f; return; }
  s = delta / maxVal;
  if (delta <= 0.000001f) { h = 0.0f; return; }
  if (maxVal == r)      h = 60.0f * fmodf(((g - b) / delta), 6.0f);
  else if (maxVal == g) h = 60.0f * (((b - r) / delta) + 2.0f);
  else                  h = 60.0f * (((r - g) / delta) + 4.0f);
  if (h < 0.0f) h += 360.0f;
}

bool hueInGreenRange(float h) {
  return (h >= HUE_MIN_DEG && h <= HUE_MAX_DEG);
}

ColorReading readAveragedColor() {
  uint32_t rSum = 0, gSum = 0, bSum = 0, cSum = 0;
  for (uint8_t i = 0; i < AVG_SAMPLES; i++) {
    uint16_t r, g, b, c;
    tcs.getRawData(&r, &g, &b, &c);
    rSum += r; gSum += g; bSum += b; cSum += c;
    delay(5);
  }
  ColorReading out;
  out.r = rSum / AVG_SAMPLES;
  out.g = gSum / AVG_SAMPLES;
  out.b = bSum / AVG_SAMPLES;
  out.c = cSum / AVG_SAMPLES;
  float sumRGB = (float)out.r + (float)out.g + (float)out.b;
  if (sumRGB < 1.0f) sumRGB = 1.0f;
  out.rn = out.r / sumRGB;
  out.gn = out.g / sumRGB;
  out.bn = out.b / sumRGB;
  rgbToHsv(out.rn, out.gn, out.bn, out.hue, out.sat, out.val);
  out.dominance = out.gn - fmaxf(out.rn, out.bn);
  return out;
}

bool isGreenEraser(const ColorReading &x) {
  if (x.c < CLEAR_MIN)             return false;
  if (x.gn < GREEN_MIN_NORM)       return false;
  if (x.rn > RED_MAX_NORM)         return false;
  if (x.bn > BLUE_MAX_NORM)        return false;
  if (x.dominance < DOMINANCE_MIN) return false;
  if (!hueInGreenRange(x.hue))     return false;
  return true;
}

void printHeader() {
  Serial.println();
  Serial.println("r,g,b,c,rNorm,gNorm,bNorm,hue,sat,val,dominance,isGreen,servoState");
  Serial.println("--------------------------------------------------------------------");
}

void printReading(const ColorReading &x, bool greenNow) {
  Serial.print(x.r);            Serial.print(",");
  Serial.print(x.g);            Serial.print(",");
  Serial.print(x.b);            Serial.print(",");
  Serial.print(x.c);            Serial.print(",");
  Serial.print(x.rn, 4);        Serial.print(",");
  Serial.print(x.gn, 4);        Serial.print(",");
  Serial.print(x.bn, 4);        Serial.print(",");
  Serial.print(x.hue, 1);       Serial.print(",");
  Serial.print(x.sat, 3);       Serial.print(",");
  Serial.print(x.val, 3);       Serial.print(",");
  Serial.print(x.dominance, 4); Serial.print(",");
  Serial.print(greenNow ? 1 : 0); Serial.print(",");
  Serial.println(servoState);
}

long degreesToDutyCycle(int deg) {
  return map(deg, 0, 180, cMinDutyCycle, cMaxDutyCycle);
}

void moveServoTo(int deg) {
  ledcWrite(cServoPin, degreesToDutyCycle(deg));
}

// -------------------- Motor functions ----------------------
void turnMotor1On() {
  digitalWrite(M1_IN1, HIGH);
  digitalWrite(M1_IN2, LOW);
  ledcWrite(M1_PWM, M1_SPEED);
}
void turnMotor1Off() {
  ledcWrite(M1_PWM, 0);
  digitalWrite(M1_IN1, LOW);
  digitalWrite(M1_IN2, LOW);
}
void turnMotor2On() {
  digitalWrite(M2_IN1, HIGH);
  digitalWrite(M2_IN2, LOW);
  ledcWrite(M2_PWM, M2_SPEED);
}
void turnMotor2Off() {
  ledcWrite(M2_PWM, 0);
  digitalWrite(M2_IN1, LOW);
  digitalWrite(M2_IN2, LOW);
}

// -------------------- Motor state machine ------------------
void updateMotors() {
  unsigned long now = millis();
  switch (motorState) {
    case M1_RUNNING:
      if (now - motorStateStart >= RUN_TIME) {
        turnMotor1Off();
        motorStateStart = now;
        motorState = GAP_TO_M2;
      }
      break;
    case GAP_TO_M2:
      if (now - motorStateStart >= GAP_TIME) {
        turnMotor2On();
        motorStateStart = now;
        motorState = M2_RUNNING;
      }
      break;
    case M2_RUNNING:
      if (now - motorStateStart >= RUN_TIME) {
        turnMotor2Off();
        motorStateStart = now;
        motorState = GAP_TO_M1;
      }
      break;
    case GAP_TO_M1:
      if (now - motorStateStart >= GAP_TIME) {
        turnMotor1On();
        motorStateStart = now;
        motorState = M1_RUNNING;
      }
      break;
  }
}
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

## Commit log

2026-09-16 Initial commit: Autonomous Sorting Robot (MSE2202)
    [Assem1.SLDASM, Base and Chasis.SLDPRT, Battery Clips.SLDDRW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]
2026-09-16 Fix broken README links by localizing images and files
    Images and attachments were hosted on GitHub's private user-attachments
    CDN tied to the school org repo, so they 404'd for anyone without
    access to that account. Moved them into readme-assets/ and switched
    the CAD/code folder links to repo-relative paths.
    [BOM.xlsx, Design-Requirements-Table.xlsx, Weekly-Gantt-Chart.xlsx]
